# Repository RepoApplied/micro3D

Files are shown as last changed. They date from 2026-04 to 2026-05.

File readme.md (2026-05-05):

# micro3D: Custom 3D-Printed Microscope for TIE Phase Retrieval

This repository contains the 3D-printable components and design files for a custom-built microscope optimized for **Transport of Intensity Equation (TIE)** phase retrieval. The design focuses on a direct ETL (Electrically Tunable Lens) configuration to minimize optical complexity and instrument footprint.

## Overview

The microscope is designed to enable axial displacement of the focal plane through an integrated ETL. This allows for the rapid acquisition of multifocal image stacks at different defocus distances without mechanical movement of the sample, which is essential for quantitative phase imaging.

### Key Features:
* **Direct ETL Configuration:** Simplified optical path to minimize aberrations.
* **Reduced Footprint:** Incorporation of two first-surface mirrors to fold the optical path and minimize the instrument's volume.
* **Phase Stability:** Validated setup that eliminates spurious quadratic phase terms during lateral sample translation.
* **Modular Design:** 3D-printed parts for easy customization and repair.

---

## System Visualization

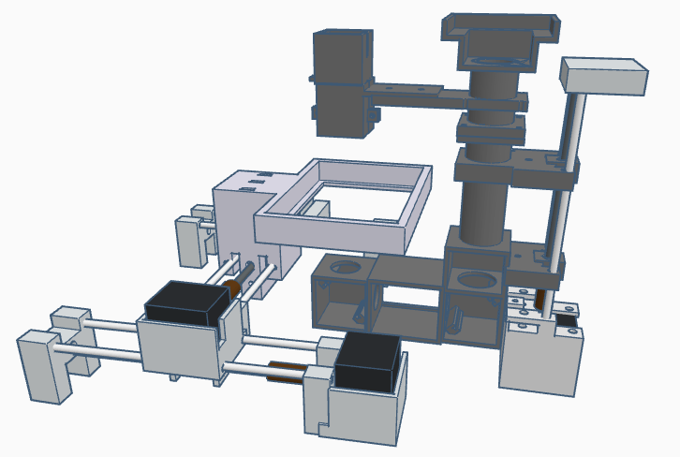
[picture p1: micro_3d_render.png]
Microscope 3D Render


*Figure 1: 3D render of the microscope components and optical layout.*

---

---

## 🔧 Assembly & Hardware Details

The mechanical assembly and electronic control are divided into two main modules to ensure precise movement and lighting management.

### Motion & Lighting Control
* **X-Y Axis Control:** Driven by **two NEMA 17 stepper motors** for precise lateral sample positioning.
* **Z-Axis & Lighting:** A **third NEMA 17 motor** controls the axial displacement (focus), while the system integrates the microscope's illumination control.
* **Electronics:**
    * **2 × Arduino Uno** boards (distributed control).
    * **Adafruit Motor Shield v2** on each Arduino for high-resolution motor stepping.

### Mechanical Specifications
* **Drive Mechanism:** 5 mm threaded rods coupled with the motors, using corresponding hexagonal nuts to translate rotational motion into linear displacement.
* **Support Rods:** 4 mm diameter **stainless steel rods** used as linear guides to ensure smooth and rigid travel.
* **Stability Tip:** It is highly recommended to mount the 3D-printed assembly within an **external aluminum frame** to guarantee system stability and minimize mechanical vibrations during image acquisition.

---

## Setup & Calibration

1.  **Mechanical Alignment:** Ensure the 4 mm stainless steel rods are perfectly parallel to prevent friction or jamming in the X, Y, and Z stages.
2.  **Motor Configuration:** One Arduino/Shield pair is dedicated to the X-Y stage, while the second pair manages the Z-axis and the illumination intensity.
3.  **Vibration Dampening:** Tighten all 5 mm nuts and ensure the aluminum structure is properly leveled.

## Software Architecture & Control Logic

The system operates through a **Master-Slave architecture** where a Python-based controller orchestrates the hardware via serial communication.

### 1. High-Level Controller (Python)
The `main_controller.py` script manages hardware synchronization:
* **Automatic Device Discovery:** Identifies `Arduino_1` (XY), `Arduino_2` (Z/Light), and the **Optotune ETL** via a handshake protocol (sending '0').
* **Asynchronous Processing:** Uses `multiprocessing` to run hardware control and the uEye camera live feed in parallel.
* **Event-Driven Input:** A keyboard listener maps specific keys to serial commands.

### 2. Firmware Logic (C++/Arduino)
Both Arduinos run a command-listener loop at **115,200 baud**.

* **Arduino 1 (XY Stage):** Handles fine stepping (10 steps) and fast travel (1000 steps) for the X and Y axes.
* **Arduino 2 (Z-Axis & Light):** Manages vertical focus displacement and toggles digital pins (8/9 and 12/13) for illumination control.

---

## ⌨️ Control Mapping Reference

| Key | Action | Target Device | Command Sent |
| :--- | :--- | :--- | :--- |
| **W / S** | Move X-Axis (Fine) | Arduino 1 | `1` / `2` |
| **A / D** | Move Y-Axis (Fine) | Arduino 1 | `3` / `4` |
| **I / K** | Move X-Axis (Fast) | Arduino 1 | `5` / `6` |
| **J / L** | Move Y-Axis (Fast) | Arduino 1 | `7` / `8` |
| **Q / E** | Move Z-Axis (Focus) | Arduino 2 | `1` / `2` |
| **U / O** | Toggle Illumination A | Arduino 2 | `3` |
| **F / T** | Toggle Illumination B | Arduino 2 | `4` |
| **Z / X** | +/- ETL Current | Optotune ETL | Serial API |
| **P** | Emergency Stop / Exit | All | — |

---

## References

If you use this design or research in your work, please cite the following publications:

* **Silva, A., Arocena, M., Hochmann, J., Fernández, A., & Alonso, J. R. (2025).** Quantitative phase microscopy for time-lapse hypoxia-induced cellular assays based on the transport of intensity equation. *Applied Optics*, 64(5), 1186-1195.

* **Silva, A., & Alonso, J. R. (2022, August).** Open source electronic platforms and 3d printing for microscopy: a cost-effective approach. In *Latin America Optics and Photonics Conference* (pp. M2C-2). Optica Publishing Group.
---

## Contents
* `/stl`: Standard Tessellation Language files for 3D printing.
* `/scad`: Original OpenSCAD or CAD source files for modifications.

---

## Requirements
* **3D Printer:** FDM or SLA (FDM recommended for structural parts).
* **Material:** PLA, PETG, or ABS.
* **Hardware:** Two first-surface mirrors, Electrically Tunable Lens (ETL), and standard optical cage components.

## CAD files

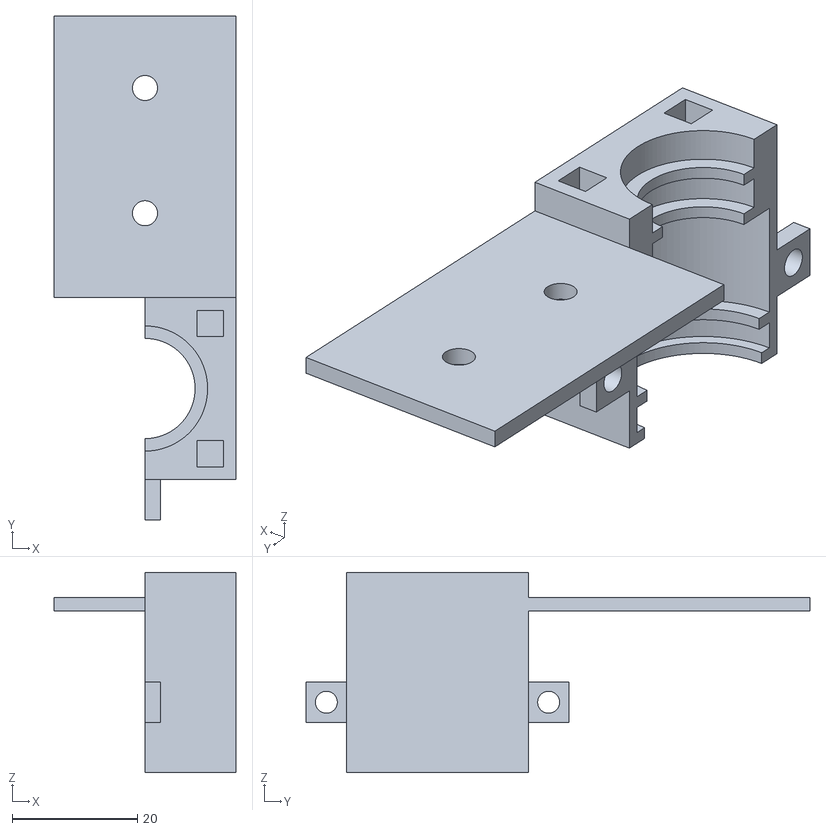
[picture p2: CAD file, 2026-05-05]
models_stl/lentes_soporte.stl
29.0 x 80.5 x 32.0

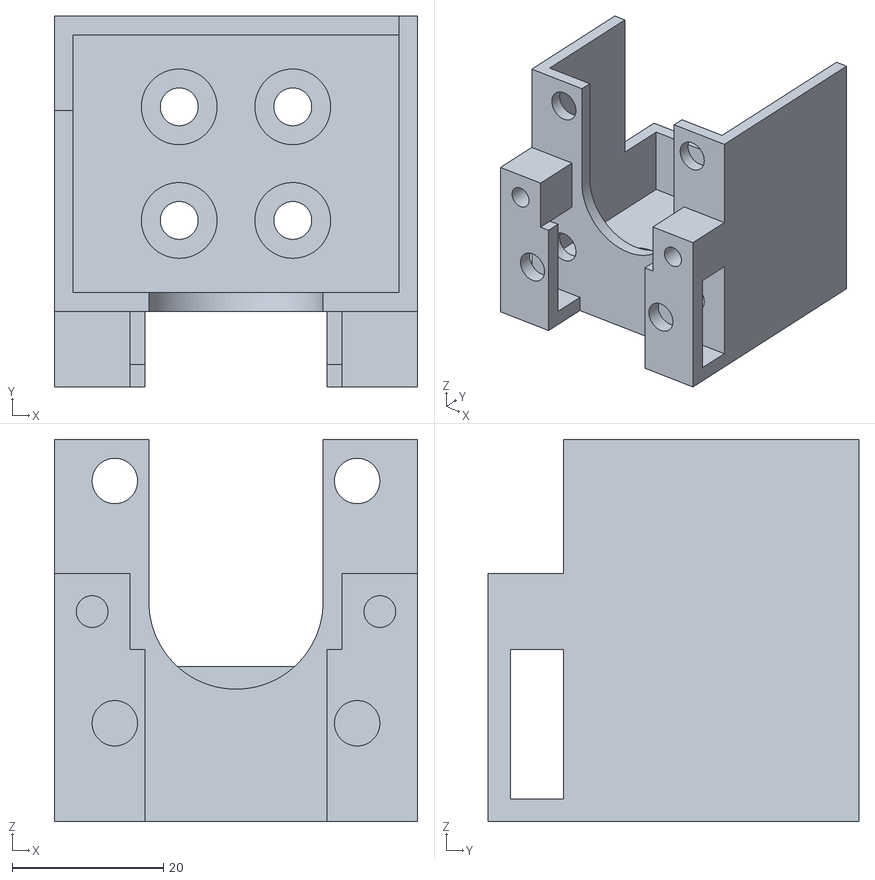
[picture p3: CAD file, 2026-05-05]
models_stl/soporte_motor_1.stl
48.0 x 49.0 x 50.5

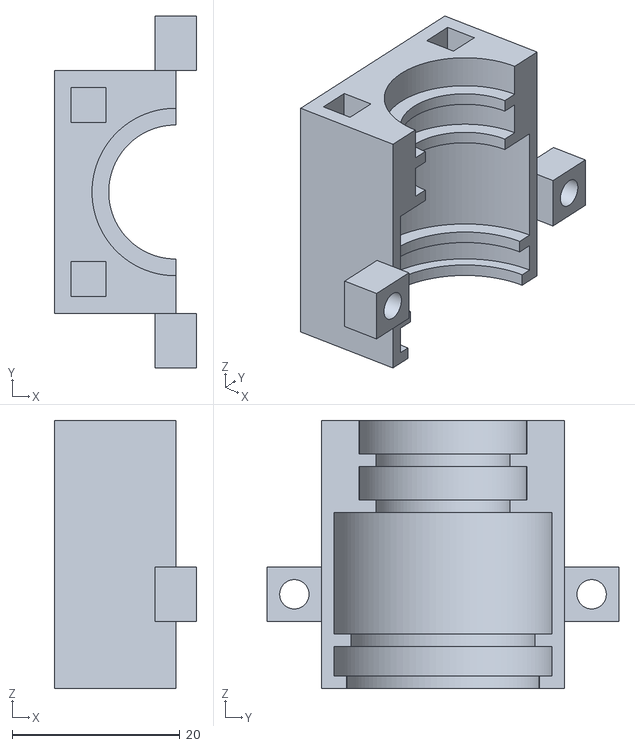
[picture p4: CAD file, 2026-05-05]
models_stl/lentes_soporte2.stl
17.0 x 42.0 x 32.0

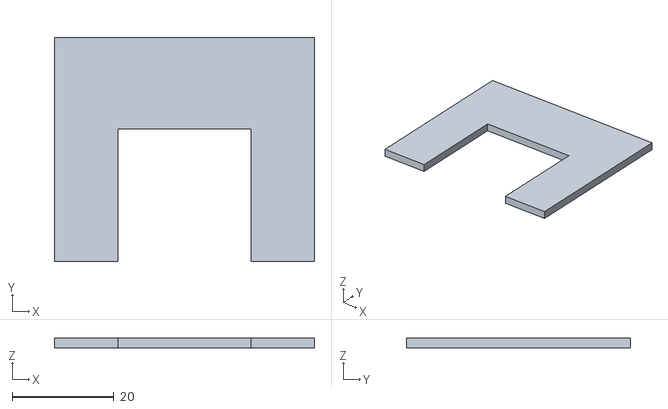
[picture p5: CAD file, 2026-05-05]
models_stl/soporte_cam.stl
51.0 x 44.0 x 2.00

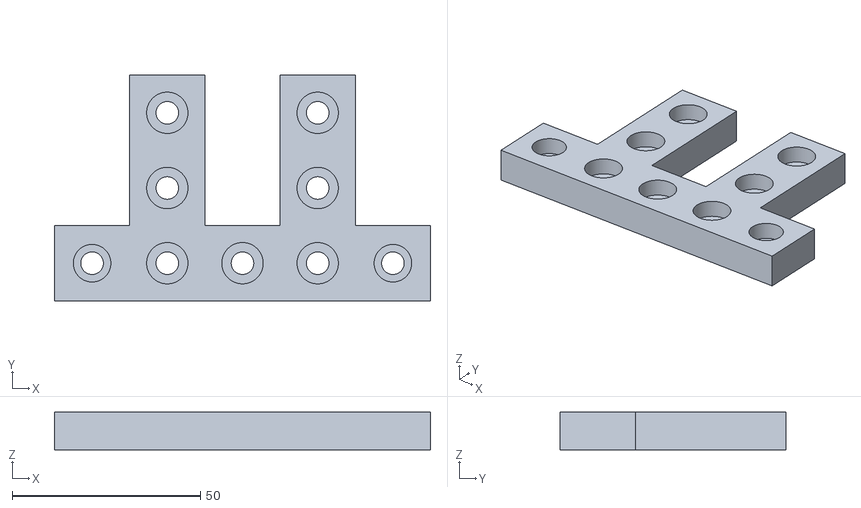
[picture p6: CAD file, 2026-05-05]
models_stl/base_motor_vertical_opuesto.stl
100.0 x 60.0 x 10.0

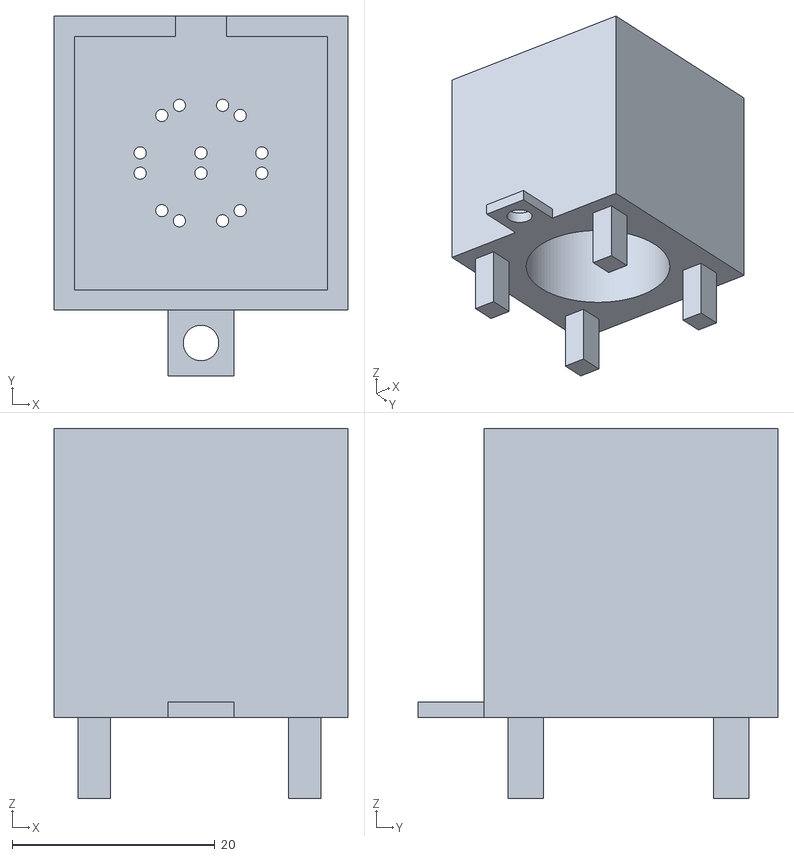
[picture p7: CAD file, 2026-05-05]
models_stl/leds_soporte.stl
29.0 x 35.5 x 36.5

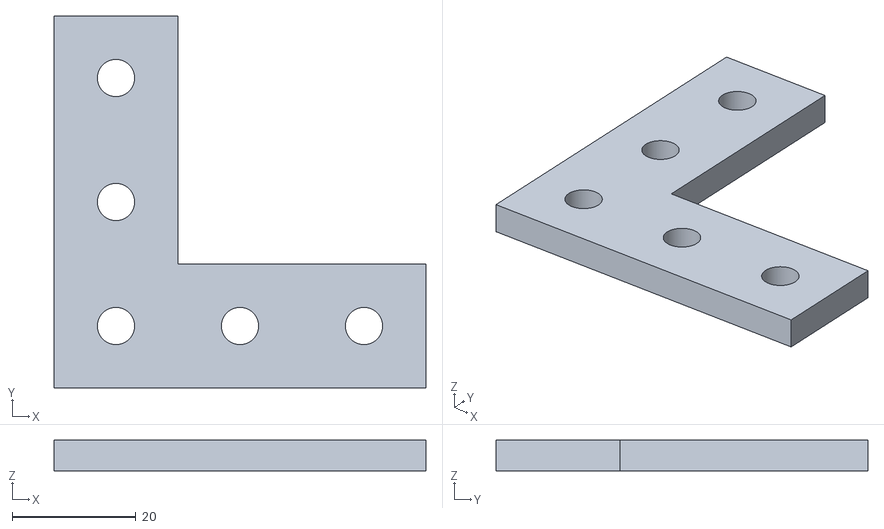
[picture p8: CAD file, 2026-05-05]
models_stl/base_motor2.stl
60.0 x 60.0 x 5.00

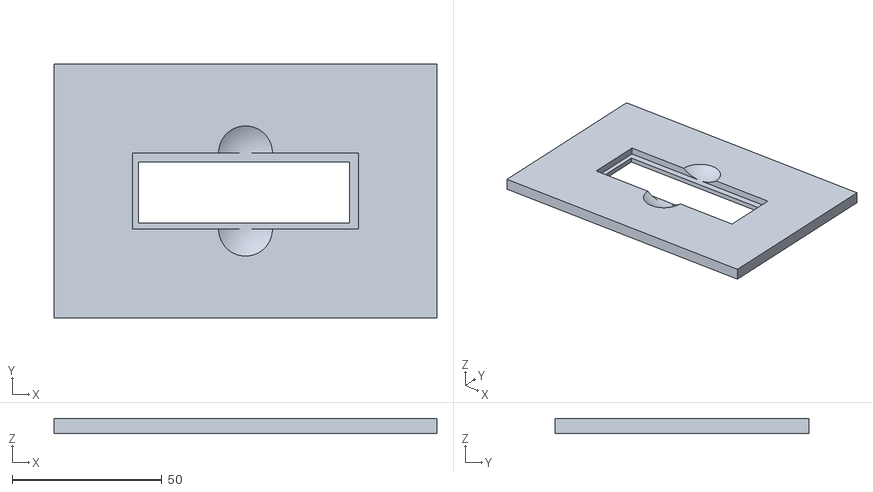
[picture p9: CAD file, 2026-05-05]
models_stl/molde_petri35mm.stl
128.0 x 85.0 x 5.00

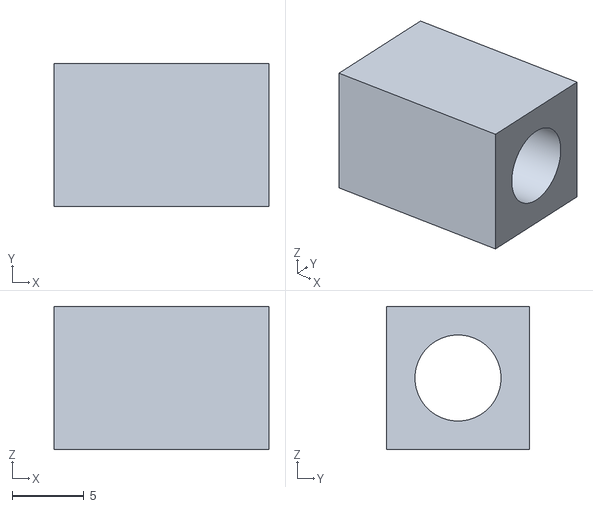
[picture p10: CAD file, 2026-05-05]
models_stl/soporte_led.stl
15.0 x 10.0 x 10.0

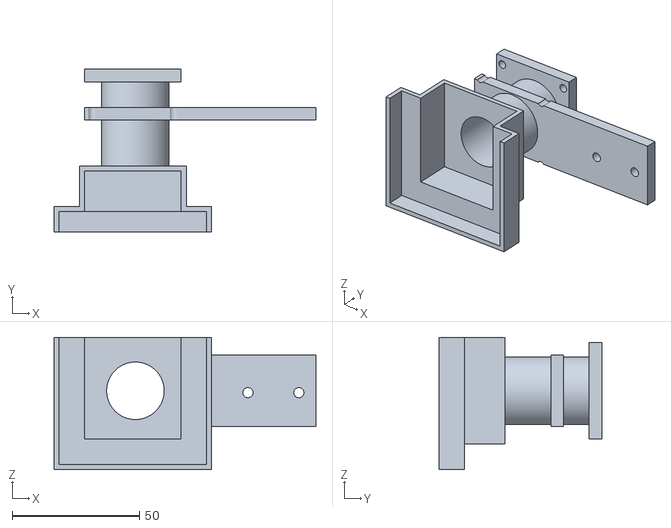
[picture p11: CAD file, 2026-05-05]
models_stl/camara.stl
103.0 x 64.0 x 52.0

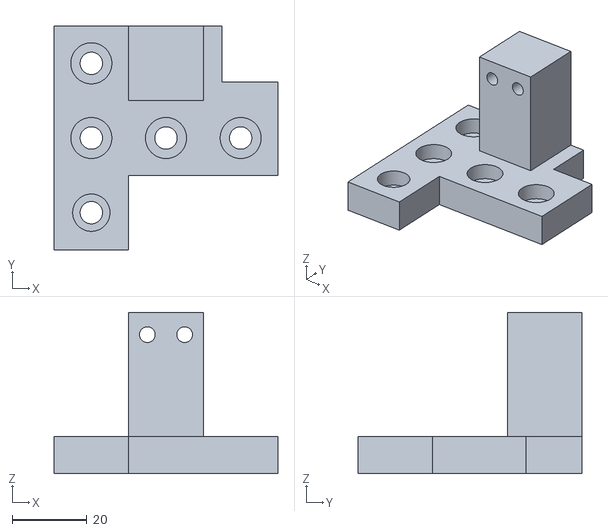
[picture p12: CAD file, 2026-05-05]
models_stl/base_opuesto4.stl
60.0 x 60.0 x 43.2

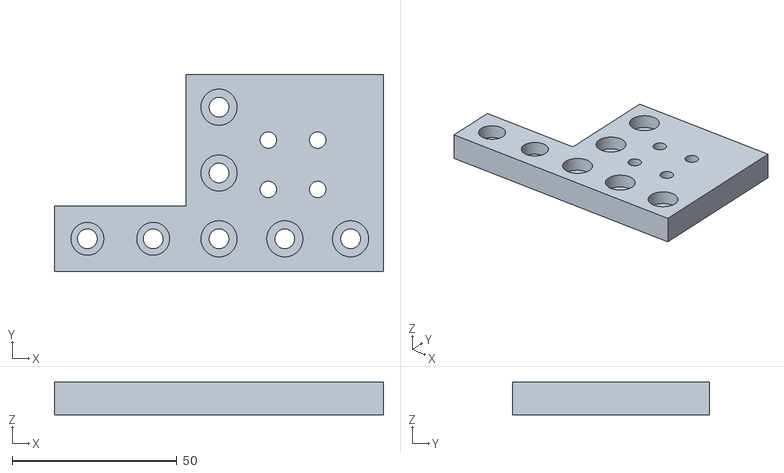
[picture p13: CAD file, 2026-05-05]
models_stl/base_motor1.stl
100.0 x 60.0 x 10.0

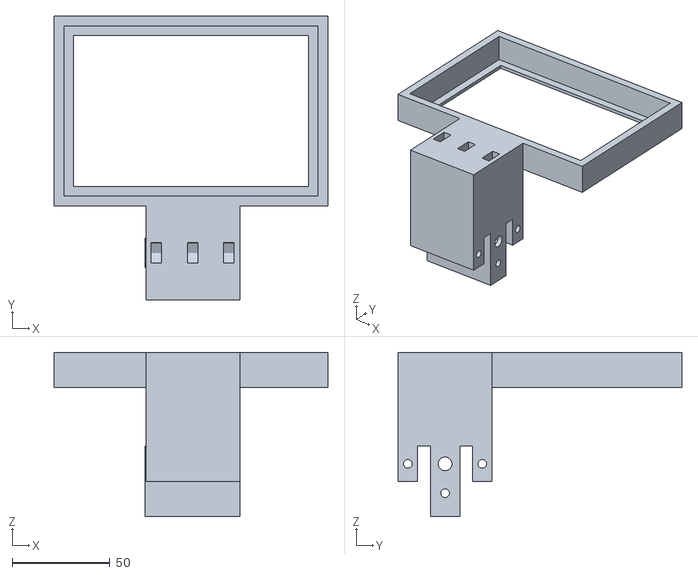
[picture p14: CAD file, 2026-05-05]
models_stl/portapocillos.stl
140.0 x 145.0 x 84.0

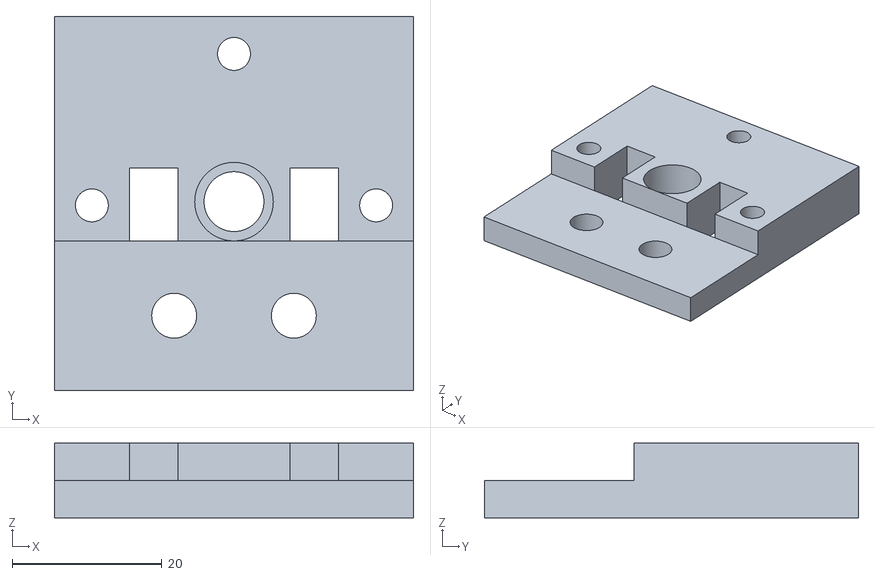
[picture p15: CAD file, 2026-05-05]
models_stl/soporte_arriba_z.stl
48.0 x 50.0 x 10.0

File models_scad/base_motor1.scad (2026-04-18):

espesor = 5;
radio_exteriores = 3;

//translate([8.5,13,espesor]) difference() {cube([48,39,espesor]);
//translate([16.5,12,0]) cylinder(h = espesor, r1 = 3, r2 = 3, $fn=100);
//translate([48-16.5,12,0]) cylinder(h = espesor, r1 = 3, r2 = 3, $fn=100);
//translate([16.5,39-12,0]) cylinder(h = espesor, r1 = 3, r2 = 3, $fn=100);
//translate([48-16.5,39-12,0]) cylinder(h = espesor, r1 = 3, r2 = 3, $fn=100);
//};


translate([0,0,0]) difference() {cube([60,60,espesor]);
    translate([10,10,0]) cylinder(h = espesor, r1 = 3, r2 = 3, $fn=100);
    translate([30,10,0]) cylinder(h = espesor, r1 = 3, r2 = 3, $fn=100);
    translate([50,10,0]) cylinder(h = espesor, r1 = 3, r2 = 3, $fn=100);
    translate([10,30,0]) cylinder(h = espesor, r1 = 3, r2 = 3, $fn=100);
    translate([10,50,0]) cylinder(h = espesor, r1 = 3, r2 = 3, $fn=100);
    
    translate([8.5,13,0]) union(){
    translate([16.5,12,0]) cylinder(h = espesor, r1 = 5, r2 = 5, $fn=100);
    translate([48-16.5,12,0]) cylinder(h = espesor, r1 = 5, r2 = 5, $fn=100);
    translate([16.5,39-12,0]) cylinder(h = espesor, r1 = 5, r2 = 5, $fn=100);
    translate([48-16.5,39-12,0]) cylinder(h = espesor, r1 = 5, r2 = 5, $fn=100);
    };
    };
    
    
translate([0,0,espesor]) difference() {cube([60,60,5]);
    translate([10,10,0]) cylinder(h = 5, r1 = 5.5, r2 = 5.5, $fn=100);
    translate([30,10,0]) cylinder(h = 5, r1 = 5.5, r2 = 5.5, $fn=100);
    translate([50,10,0]) cylinder(h = 5, r1 = 5.5, r2 = 5.5, $fn=100);
    translate([10,30,0]) cylinder(h = 5, r1 = 5.5, r2 = 5.5, $fn=100);
    translate([10,50,0]) cylinder(h = 5, r1 = 5.5, r2 = 5.5, $fn=100);
    
    translate([8.5,13,0]) union(){
    translate([16.5,12,0]) cylinder(h = 5, r1 = 2.5, r2 = 2.5, $fn=100);
    translate([48-16.5,12,0]) cylinder(h = 5, r1 = 2.5, r2 = 2.5, $fn=100);
    translate([16.5,39-12,0]) cylinder(h = 5, r1 = 2.5, r2 = 2.5, $fn=100);
    translate([48-16.5,39-12,0]) cylinder(h = 5, r1 = 2.5, r2 = 2.5, $fn=100);
    };
    };
    
    
translate([-40,0,0]) difference() {cube([40,20,espesor]);
    translate([10,10,0]) cylinder(h = espesor, r1 = 3, r2 = 3, $fn=100);
    translate([30,10,0]) cylinder(h = espesor, r1 = 3, r2 = 3, $fn=100);
  
    };
    
    
translate([-40,0,espesor]) difference() {cube([40,20,espesor]);
    translate([10,10,0]) cylinder(h = espesor, r1 = 5, r2 = 5, $fn=100);
    translate([30,10,0]) cylinder(h = espesor, r1 = 5, r2 = 5, $fn=100);
  
    };    

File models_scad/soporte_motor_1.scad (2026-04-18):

espesor_motor_1 = 2.5;
radio_exteriores = 3;
radio_big = 23/2;

// corregir dimensiones

translate([0,0,5]) union(){
translate([0,0,-espesor_motor_1]) difference() {cube([48,39,2*espesor_motor_1]);
translate([16.5,12,0]) cylinder(h = 2*espesor_motor_1, r1 = 5, r2 = 5, $fn=100);
translate([48-16.5,12,0]) cylinder(h = 2*espesor_motor_1, r1 = 5, r2 = 5, $fn=100);
translate([16.5,39-12,0]) cylinder(h = 2*espesor_motor_1, r1 = 5, r2 = 5, $fn=100);
translate([48-16.5,39-12,0]) cylinder(h = 2*espesor_motor_1, r1 = 5, r2 = 5, $fn=100);
};


translate([0,0,-5]) difference() {cube([48,39,espesor_motor_1]);
translate([16.5,12,0]) cylinder(h = espesor_motor_1, r1 = 2.5, r2 = 2.5, $fn=100);
translate([48-16.5,12,0]) cylinder(h = espesor_motor_1, r1 = 2.5, r2 = 2.5, $fn=100);
translate([16.5,39-12,0]) cylinder(h = espesor_motor_1, r1 = 2.5, r2 = 2.5, $fn=100);
translate([48-16.5,39-12,0]) cylinder(h = espesor_motor_1, r1 = 2.5, r2 = 2.5, $fn=100);
};

difference(){translate([0,0,espesor_motor_1]) cube([espesor_motor_1,36.5,43]);
translate([0,39-10-2.5,2.5+43-30]) cube([2.5,10,30]);};

translate([48-2.5,0,espesor_motor_1]) cube([espesor_motor_1,39,43]);
translate([0,39-2.5,espesor_motor_1]) cube([48,espesor_motor_1,13]);


translate([2.5,2.5,2.5]) rotate(a = +90,v=[1,0,0]) difference(){cube([43,43,espesor_motor_1]);
translate([5.5,5.5,0]) cylinder(h = espesor_motor_1, r1 = radio_exteriores, r2 = radio_exteriores, $fn=100);
translate([43-5.5,5.5,0]) cylinder(h = espesor_motor_1, r1 = radio_exteriores, r2 = radio_exteriores, $fn=100);
translate([5.5,43-5.5,0]) cylinder(h = espesor_motor_1, r1 = radio_exteriores, r2 = radio_exteriores, $fn=100);
translate([43-5.5,43-5.5,0]) cylinder(h = espesor_motor_1, r1 = radio_exteriores, r2 = radio_exteriores, $fn=100);   
translate([43/2,43/2,0]) cylinder(h = espesor_motor_1, r1 = radio_big, r2 = radio_big, $fn=100);   
translate([43/2-radio_big,43/2,0])cube([23,43/2,espesor_motor_1]);    };



//agregar soporte de guias



translate([0,-10,45.5/2-5]) difference(){cube([10,10,10]);
translate([5,15,5]) rotate(a = 90, v=[1,0,0]) cylinder(h = 15 , r1 = 2.1, r2 = 2.1, $fn = 100);
};

translate([38,-10,45.5/2-5]) difference(){cube([10,10,10]);
translate([5,15,5]) rotate(a = 90, v=[1,0,0]) cylinder(h = 15 , r1 = 2.1, r2 = 2.1, $fn = 100);
};


difference(){translate([0,-10,-5]) cube([12,3,45.5/2]);
translate([5.5+2.5,-5,5.5+2.5]) rotate(a = 90, v=[1,0,0]) cylinder(h = 9 , r1 = 3, r2 = 3, $fn = 100);
};
difference(){translate([48-12,-10,-5]) cube([12,3,45.5/2]);
translate([48-5.5-2.5,-5,5.5+2.5]) rotate(a = 90, v=[1,0,0]) cylinder(h = 9 , r1 = 3, r2 = 3, $fn = 100);
};


translate([0,-10,-5]) cube([12,10,3]) ;
translate([48-12,-10,-5]) cube([12,10,3]) ;
};



///// corregir el tamaño
///// agregar base pequeña para

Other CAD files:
models_stl/soporte_espejos.stl
models_stl/caja_cables_tapa.stl
models_stl/uniones_barras_vert.stl
models_stl/union-motor-rosca.stl
models_scad/base_motor2.scad
models_scad/base_motor_vertical_opuesto.scad
models_scad/ajuste_ETL.scad
models_scad/base_opuesto3.scad
models_scad/base_opuesto4.scad
models_scad/caja_cables.scad
models_scad/caja_cables_tapa.scad
models_scad/camara.scad
models_scad/esquema_optics.scad
models_scad/leds_soporte.scad
models_scad/lentes_soporte.scad
models_scad/lentes_soporte2.scad
models_scad/modulo_fluo.scad
models_scad/molde_petri35mm.scad
models_scad/portapocillos.scad
models_scad/soporte_arriba_aluminio.scad
models_scad/soporte_arriba_z.scad
models_scad/soporte_cam.scad
models_scad/soporte_espejos.scad
models_scad/soporte_guia_opuesto_arriba.scad
models_scad/soporte_led.scad
models_scad/soporte_motor_2.scad
models_scad/soporte_motor_z.scad
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

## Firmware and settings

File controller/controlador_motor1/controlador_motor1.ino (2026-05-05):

/* 
This is a test sketch for the Adafruit assembled Motor Shield for Arduino v2
It won't work with v1.x motor shields! Only for the v2's with built in PWM
control

For use with the Adafruit Motor Shield v2 
---->	http://www.adafruit.com/products/1438
*/


#include <Wire.h>
#include <Adafruit_MotorShield.h>


// Create the motor shield object with the default I2C address
Adafruit_MotorShield AFMS = Adafruit_MotorShield(); 
// Or, create it with a different I2C address (say for stacking)
// Adafruit_MotorShield AFMS = Adafruit_MotorShield(0x61); 

// Connect a stepper motor with 200 steps per revolution (1.8 degree)
// to motor port #2 (M3 and M4)
Adafruit_StepperMotor *myMotorx = AFMS.getStepper(200, 1);
Adafruit_StepperMotor *myMotory = AFMS.getStepper(200, 2);

int x ; // for incoming serial data
int y = 1 ; // for incoming serial data

void setup() {
 Serial.begin(115200);
 Serial.setTimeout(1);

  AFMS.begin();  // create with the default frequency 1.6KHz
  //AFMS.begin(1000);  // OR with a different frequency, say 1KHz
  
  myMotorx->setSpeed(10);  // 10 rpm   
  myMotory->setSpeed(10);  // 10 rpm   


}

void loop() {
  //Serial.println("Single coil steps");

  while (!Serial.available());
  x = Serial.readString().toInt();
  Serial.print(x + 1);

    
  // read the incoming byte:
  if  (x== 1) {
  myMotorx->step(10, FORWARD, SINGLE); 
  };    
  if  (x== 2) {
  myMotorx->step(10, BACKWARD, SINGLE); 
  };    
  if  (x== 3) {
  myMotory->step(10, FORWARD, SINGLE); 
  };    
  if  (x== 4) {
  myMotory->step(10, BACKWARD, SINGLE); 
  };    
  if  (x== 5) {
  myMotorx->setSpeed(50);  // 10 rpm   
  myMotorx->step(1000, FORWARD, SINGLE); 
  myMotorx->setSpeed(10);  // 10 rpm   
  };    
  if  (x== 6) {
  myMotorx->setSpeed(50);  // 10 rpm   
  myMotorx->step(1000, BACKWARD, SINGLE); 
  myMotorx->setSpeed(10);  // 10 rpm   
  };    
  if  (x== 7) {
  myMotory->setSpeed(50);  // 10 rpm   
  myMotory->step(1000, FORWARD, SINGLE); 
  myMotory->setSpeed(10);  // 10 rpm   
  };    
  if  (x== 8) {
  myMotory->setSpeed(50);  // 10 rpm   
  myMotory->step(1000, BACKWARD, SINGLE); 
  myMotory->setSpeed(10);  // 10 rpm   
  };    
  delay(5);

  

}

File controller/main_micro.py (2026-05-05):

import serial
import time
import cv2
import numpy as np
from multiprocessing import Process
from pynput import keyboard as kb
from opto import Opto
from pyueye import ueye

def list_serial_ports():
    """
    Scans and returns a list of available COM ports.
    """
    ports = ['COM%s' % (i + 1) for i in range(256)]
    found_ports = []
    for port in ports:
        try:
            s = serial.Serial(port)
            s.close()
            found_ports.append(port)
        except (OSError, serial.SerialException):
            pass
    return found_ports

def get_port_id(device_serial):
    """
    Sends an identification signal to a serial device and returns its response.
    """
    time.sleep(1)
    device_serial.write(bytes('0', 'utf-8'))
    time.sleep(1)
    data = device_serial.readline()
    return data

def find_device_port(device_name):
    """
    Identifies the specific COM port for Arduino1, Arduino2, or the ETL 
    based on their unique identification strings.
    """
    available_ports = list_serial_ports()

    for com in available_ports:
        try:
            ser = serial.Serial(port=com, baudrate=115200, timeout=.1)
            time.sleep(1)
            data = get_port_id(ser)
            
            # Logic for identifying each device
            if device_name == 'ard1' and data == b'1':
                ser.close()
                print(f"{device_name} connected on {com}")
                return com
            if device_name == 'ard2' and data == b'2':
                ser.close()
                print(f"{device_name} connected on {com}")
                return com
            if device_name == 'ETL' and data == b'E\x03r\x91\r\n':
                ser.close()
                print(f"{device_name} connected on {com}")
                return com
            ser.close()
        except Exception as e:
            print(f"Error checking port {com}: {e}")
            
    print(f"Device {device_name} not found.")
    return -1

def send_command(command, device_serial):
    """
    Sends a string command to the specified serial device.
    """
    device_serial.write(bytes(command, 'utf-8'))
    time.sleep(0.05)
    return 0

def on_key_press(key, arduino1, arduino2, etl, mem_ptr, width, height, bitspixel, lineinc, directory, index):
    """
    Keyboard listener handler. Controls X, Y, Z movement, ETL current, and system shutdown.
    """
    current_etl_ma = etl.current()

    # System Exit
    if key == kb.KeyCode.from_char('p'):
        arduino1.close()
        arduino2.close()
        etl.close(soft_close=True)
        print("Shutting down system...")
        return False

    # Arduino 1 Controls (typically X-Y Axis)
    mapping_ard1 = {
        'a': '1', 'd': '2', 's': '3', 'w': '4',
        'j': '5', 'l': '6', 'k': '7', 'i': '8'
    }
    
    # Arduino 2 Controls (typically Z-Axis and Illumination)
    mapping_ard2 = {
        'q': '1', 'e': '2', # Z movement
        'u': '5', 'o': '6', # Illumination
        'f': '3', 't': '4'  # Extras
    }

    char = getattr(key, 'char', None)
    
    if char in mapping_ard1:
        send_command(mapping_ard1[char], arduino1)
    
    if char in mapping_ard2:
        send_command(mapping_ard2[char], arduino2)

    # ETL Current Control (Focusing)
    if char == 'x': # Decrease current
        if current_etl_ma > 2:
            current_etl_ma -= 2
            etl.current(current_etl_ma)
            print(f"ETL Current: {current_etl_ma} mA")

    if char == 'z': # Increase current
        if current_etl_ma < 290:
            current_etl_ma += 2
            etl.current(current_etl_ma)
            print(f"ETL Current: {current_etl_ma} mA")

    return True

def run_main_controller():
    """
    Main function to initialize hardware (Arduinos, ETL, and uEye Camera) 
    and start the keyboard control loop.
    """
    # 1. Hardware Discovery
    com_a1 = find_device_port('ard1')
    com_a2 = find_device_port('ard2')
    com_etl = find_device_port('ETL')

    if com_a1 == -1 or com_a2 == -1 or com_etl == -1:
        print("Hardware initialization failed. Check connections.")
        return False

    # 2. Hardware Initialization
    etl = Opto(port=com_etl)
    etl.connect()
    etl.current(0)
    
    arduino1 = serial.Serial(port=com_a1, baudrate=115200, timeout=.1)
    arduino2 = serial.Serial(port=com_a2, baudrate=115200, timeout=.1)
    time.sleep(1)

    # 3. uEye Camera Initialization
    hcam = ueye.HIDS(0)
    ueye.is_InitCamera(hcam, None)
    ueye.is_SetColorMode(hcam, ueye.IS_CM_BGR8_PACKED)

    # Set Region of Interest (ROI)
    width, height = 1280, 1080
    rect_aoi = ueye.IS_RECT()
    rect_aoi.s32X = rect_aoi.s32Y = ueye.int(0)
    rect_aoi.s32Width, rect_aoi.s32Height = ueye.int(width), ueye.int(height)
    ueye.is_AOI(hcam, ueye.IS_AOI_IMAGE_SET_AOI, rect_aoi, ueye.sizeof(rect_aoi))

    # Memory Allocation
    mem_ptr = ueye.c_mem_p()
    mem_id = ueye.int()
    bitspixel = 24
    ueye.is_AllocImageMem(hcam, width, height, bitspixel, mem_ptr, mem_id)
    ueye.is_SetImageMem(hcam, mem_ptr, mem_id)
    ueye.is_CaptureVideo(hcam, ueye.IS_DONT_WAIT)

    lineinc = width * int((bitspixel + 7) / 8)
    save_directory = 'C:\\Users\\aleja\\OneDrive\\Documents\\Doctorado\\Setiembre2022\\'
    img_index = 0

    print('System Ready. Use keyboard to control.')

    # 4. Control Loop
    with kb.Listener(on_press=lambda key: on_key_press(
            key, arduino1, arduino2, etl, mem_ptr, width, height, 
            bitspixel, lineinc, save_directory, img_index)) as listener:
        listener.join()

    return True

def run_ueye_camera_preview():
    """
    Optional process to display the uEye camera live feed in a separate window.
    """
    hcam = ueye.HIDS(0)
    ueye.is_InitCamera(hcam, None)
    ueye.is_SetColorMode(hcam, ueye.IS_CM_BGR8_PACKED)

    width, height = 1280, 1080
    mem_ptr = ueye.c_mem_p()
    mem_id = ueye.int()
    bitspixel = 24
    
    ueye.is_AllocImageMem(hcam, width, height, bitspixel, mem_ptr, mem_id)
    ueye.is_SetImageMem(hcam, mem_ptr, mem_id)
    ueye.is_CaptureVideo(hcam, ueye.IS_DONT_WAIT)
    lineinc = width * int((bitspixel + 7) / 8)

    while True:
        img = ueye.get_data(mem_ptr, width, height, bitspixel, lineinc, copy=True)
        img = np.reshape(img, (height, width, 3))
        cv2.imshow('uEye Live Feed (Press O to exit)', img)
        
        if cv2.waitKey(1) & 0xFF == ord('o'):
            break

    cv2.destroyAllWindows()
    ueye.is_StopLiveVideo(hcam, ueye.IS_FORCE_VIDEO_STOP)
    ueye.is_ExitCamera(hcam)

if __name__ == '__main__':
    # Start the controller as the main process
    main_process = Process(target=run_main_controller)
    main_process.start()
    main_process.join()

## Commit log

2026-04-18 all files
    [ajuste_ETL.scad, base_motor1.scad, base_motor2.scad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]
2026-05-05 Solucionado el repo embebido en modelo_scad
    [ajuste_ETL.scad, ajuste_ETL.stl, base_motor1.scad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]
2026-05-05 chore: refactor repo
    [ajuste_ETL.scad, ajuste_ETL.stl, base_motor1.scad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]
